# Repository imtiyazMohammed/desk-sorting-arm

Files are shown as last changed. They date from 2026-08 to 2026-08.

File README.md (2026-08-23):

# Autonomous Desk-Sorting Robotic Arm — Phase A

https://github.com/user-attachments/assets/2be9d9cc-dfaf-4284-88d5-a9f24a1ce587



Kinematics simulation (Phase A), computer-vision foundation (Phase B), and
parametric CAD (Phase D). No hardware required to run anything in this
repository.

**Requires Python 3.10-3.14.** `build123d` (Phase D parametric CAD) declares
`requires-python ">=3.10,<3.15"`, so the Python 3.9 support present through
Phase A has been dropped. Raspberry Pi OS Bookworm ships 3.11 and Trixie ships
3.13, so 3.9 is not needed for the deployment target. CI covers 3.10-3.13.

## Quickstart

```bash
# 1. Install dependencies
python3 -m pip install -r requirements.txt

# 2. Run the test suite (449 tests, ~11 seconds)
python3 -m pytest tests/ -v

# 3. Try the module smoke tests
python3 -m src.geometry              # geometry + hardware summary
python3 -m src.forward_kinematics    # FK sanity checks
python3 -m src.inverse_kinematics    # IK sample solves
python3 -m src.trajectory            # trajectory profiling
python3 -m src.image_source          # synthetic camera frames
python3 -m src.camera_calibration    # synthetic calibration vs ground truth

# 4. Generate the CAD parts
python3 -m cad.base_pedestal            # monolithic U-clamp + servo turret
python3 -m cad.desk_clamp_knob          # hand knob
python3 -m cad.desk_clamp_pressure_foot # foot on the clamp screw's tip
python3 -m cad.assembly_preview         # whole assembly on a desk: STL + PNG
#   ... each takes --report (dimensions only) and --output PATH

# 5. Manual hardware tools (need a webcam; not part of the test suite)
python3 scripts/preview_camera.py
python3 scripts/calibrate_camera.py
#   ... both take --synthetic to run without a camera

# 6. Read the proof-of-concept document
docs/PROOF_OF_CONCEPT.md
```

Heavy vision dependencies (`ultralytics`, which pulls in torch) are kept out of
`requirements.txt` until Session B.2 actually imports them:

```bash
python3 -m pip install -r requirements-vision.txt
```

## Repository layout

```
desk_arm/
├── src/
│   ├── geometry.py             # ArmGeometry + hardware specs (source of truth)
│   ├── forward_kinematics.py   # Hand-derived FK using homogeneous transforms
│   ├── arm_chain.py            # ikpy Chain constructor
│   ├── inverse_kinematics.py   # IK with reachability + singularity checks
│   ├── trajectory.py           # Trapezoidal velocity profiler
│   ├── visualizer.py           # 3D matplotlib rendering
│   ├── image_source.py         # ImageSource ABC + synthetic and webcam sources
│   └── camera_calibration.py   # Chessboard intrinsics + synthetic target
├── cad/
│   ├── base_pedestal.py        # Monolithic U-clamp + servo turret (build123d)
│   ├── desk_clamp_knob.py      # Fluted hand knob
│   ├── desk_clamp_pressure_foot.py  # Foot on the clamp screw's tip
│   ├── assembly_preview.py     # All parts placed on a desk (STL + PNG)
│   ├── _design.py              # Shared DesignStatus / DesignRuleError
│   ├── _primitives.py          # Shared solids (hex_prism)
│   ├── output/                 # Generated STLs
│   └── README.md               # Parametric approach, clamp design, assembly
├── scripts/
│   ├── preview_camera.py       # Manual webcam check, not run by CI
│   └── calibrate_camera.py     # Interactive intrinsic calibration
├── tests/
│   ├── test_kinematics.py      # 35 tests - Phase A kinematics
│   ├── test_image_source.py    # 71 tests - Session B.1 image acquisition
│   ├── test_camera_calibration.py  # 100 tests - Session B.2 calibration
│   └── test_cad.py             # 243 tests - Sessions D.1/D.1b/D.1c/D.1d parametric CAD
├── docs/
│   ├── PROOF_OF_CONCEPT.md     # Design + math + validation
│   └── figures/                # Generated diagrams
├── requirements.txt
├── requirements-vision.txt     # Deferred: ultralytics / torch
└── README.md
```

## Design constraints locked in Phase A

| Parameter | Value | Reason |
|---|---|---|
| DOF | 5 (base yaw, shoulder, elbow, wrist pitch, wrist roll) | Enables angled grasps + monitor cleaning |
| Mount position | Center of long desk edge (1200×600 mm desk) | Halves worst-case reach vs corner mount |
| L1 (upper arm) | 400 mm | |
| L2 (forearm) | 350 mm | |
| L3 (wrist → TCP) | 200 mm | |
| Base height | 100 mm | |
| Total reach | 950 mm | Covers 848.5 mm desk diagonal with 12% margin |
| Servos | DS3218 (5×) | 21.5 kg·cm at 6.8 V, digital metal-gear |
| Base pedestal | 70 mm tall, 85.3 mm body | `base_height_mm` 100 − 30 mm stack allowance |
| Desk mount | Monolithic M8 U-clamp, 45 mm throat | No drilling; fits 15–35 mm desks, repositionable |

## Known outstanding items (deferred to later phases)

- **Shoulder torque budget**: 950 mm arm exceeds DS3218 20 kg·cm rating. To be resolved in Phase C via 2:1 gear reduction or dual-servo shoulder.
- **Singularity threshold**: Currently unit-inconsistent (mm-scaled Jacobian). To be normalized before deployment.
- **Orientation IK**: Position-only solves for now. Full pose IK (with grasp orientation) belongs to the grasp planner in Phase E.
- **Unverified servo dimensions**: The DS3218 body envelope is datasheet-confirmed, but its mounting-flange geometry and output-shaft placement are placeholders. See `ServoSpec.UNVERIFIED_FIELDS` and [cad/README.md](cad/README.md); measure a real unit before printing for final assembly.
- **Provisional base stack**: The 6 mm turntable plate and 24 mm shoulder bracket rise that set the pedestal height are estimates, replaced in Sessions D.2/D.3.

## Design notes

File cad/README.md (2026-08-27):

# Parametric CAD

Mechanical parts for the desk-sorting arm, modelled in
[build123d](https://build123d.readthedocs.io/) (a Python CAD library over the
OpenCASCADE kernel).

## The rule: no dimensions live here

Every part in this package derives its dimensions from `src/geometry.py`:

- **`DEFAULT_ARM`** (`ArmGeometry`) — kinematic lengths, the base height
  budget, the base's position on the desk, and the mass estimates the mount is
  sized against.
- **`DEFAULT_HARDWARE`** (`HardwareSpec`) — off-the-shelf component envelopes:
  the DS3218 servo, the 6806ZZ yaw bearing and 608ZZ shoulder idler, the servo
  horn, the M8 desk clamp, print clearances.

No module in `cad/` declares a physical dimension of its own. This is the same
discipline that keeps `arm_chain.py` building its ikpy chain programmatically
instead of from a URDF file: one number, one place, and a change propagates
atomically instead of drifting.

The practical consequence: to make the clamp fit a different servo or a thicker
desk, edit `src/geometry.py`. Do not edit `cad/base_pedestal.py`.

## Regenerating STLs

```bash
python3 -m cad.base_pedestal               # -> cad/output/base_pedestal.stl
python3 -m cad.desk_clamp_knob             # -> cad/output/desk_clamp_knob.stl
python3 -m cad.desk_clamp_pressure_foot    # -> cad/output/desk_clamp_pressure_foot.stl
python3 -m cad.yaw_turntable               # -> cad/output/yaw_turntable.stl
python3 -m cad.shoulder_bracket            # -> shoulder_bracket.stl + shoulder_idler_plug.stl
python3 -m cad.upper_arm                   # -> cad/output/upper_arm.stl
python3 -m cad.assembly_preview            # -> assembly_preview.stl + .png
```

Each module takes `--report` (print resolved dimensions, export nothing) and
`--output PATH`. Run `--report` after changing anything in `src/geometry.py` to
see what moved.

---

## Why a monolithic U-clamp

Session D.1 bolted a flange to the desk through four M4 holes — which meant
drilling the desk. D.1b replaced that with a clamp, but built it as a cylinder
with a small horizontal wing bolted down beside it: a tower with a side arm,
not a clamp. **Session D.1c is a full rewrite as a single C-profile body**, the
shape a monitor-arm clamp actually uses:

```
                      +----------+  z = +70   bearing seat in the top face
                      |  servo   |
                      |  turret  |
      +---------------+----------+---------+  z = +15   top arm
      |///|    pads       cavity opening   |  z =   0   desk surface
      |///+-------------------------------+
      |///|                                |
      |sp |          throat (desk)         |
      |ine|                                |
      |///+-------------------------------+  z = -45   bottom arm top
      |///|         nut pocket    O screw  |
      +---+-------------------------------+  z = -60   bottom arm underside
       -50  -35    -30                   +30
                    ^ desk seats here
```

Everything is one solid: top arm, spine, bottom arm, servo turret and both
gussets. There is no bolted joint anywhere in the load path.

The servo/bearing internals — cavity, retention shelf, shaft bore, seat — are
carried over from D.1 unchanged; `test_pedestal_internals_survived_the_u_clamp_rewrite`
pins those dimensions so a future edit cannot quietly disturb them.

---

## Three specified numbers that could not be built

The design-rule checks and a cross-section render caught three physical
impossibilities in the D.1c brief. All are documented here rather than
silently worked around.

### 1. A 15 mm top arm cannot contain a 40.5 mm servo

`top_arm_thickness_mm = 15.0` was specified as including the servo cavity. A
DS3218 is 40.5 mm tall and needs **55.5 mm** of housing once print clearance,
the shaft boss, a ceiling and the bearing seat are counted.

**Resolved** by keeping the arm at 15 mm and raising a **turret** from it to
the full 70 mm pedestal height. This is what the brief's own sketch showed
(the servo box is drawn above the arm line), it preserves the thin C-profile,
and the 70 mm budget from `base_height_mm − BaseStack.allowance_mm` accepts it
exactly. Thickening the arm instead would have made a slab and tripled its
material.

### 2. The servo cavity and the desk pad both wanted the same face

The cavity has to open on the top arm's underside so the servo can be inserted
from below onto its retention shelf. But that face is also what rests on the
desk and carries the anti-slip pad. A 40 × 40 mm pad has nowhere to go: the
opening lands mid-face, leaving 15.75 mm strips.

**Resolved** with **two pad strips flanking the opening**, 15.75 × 78.50 mm
each — 2473 mm² total, more contact than the single 40 × 40 pad (1600 mm²) it
replaced, and better placed, since it straddles the yaw axis instead of sitting
to one side.

### 3. A 20 mm pad recess cannot sit on an 8 mm screw tip

**Resolved** with a small printed **pressure foot** (`desk_clamp_pressure_foot.py`)
that threads onto the screw's tip and carries the pad. See below.

### And one the cross-section caught

The upper gusset hangs into the throat beside the spine, so the desk's edge
comes to rest **against the gusset, not the spine**. With the spine placed at
the nominal offset, the yaw axis would have ended up 25 mm from the desk edge
rather than the specified 30 mm.

**Resolved** by treating the gusset line as the real desk seating plane and
placing the spine one gusset further out (`spine_inner_x = desk_seat_x −
gusset_size`). `test_the_gusset_defines_where_the_desk_stops` holds it.

---

## Parts

### `base_pedestal.py` — the U-clamp

| | |
|---|---|
| Overall envelope | 80.00 (X) × 82.50 (Y) × 129.50 (Z) mm |
| Desk seats at | x = −30.00 mm (yaw axis at x = 0) |
| Top arm | x −35 … +30, z 0 … 15 |
| Spine | x −50 … −35, z −60 … +15 |
| Bottom arm | x −35 … +30, z −60 … −45 |
| Throat | 45.0 mm, for 15–35 mm desks |
| Servo turret | x ±24.95, y −41.25 … +24.95, z 15 … 69.5 |
| Servo cavity | 20.50 (X) × 40.50 (Y) body, 54.50 (Y) ear slot |
| Bearing seat | Ø41.90 × 6.50 mm deep (6806ZZ since D.2a) |
| Anti-slip pads | 2 × 15.75 × 78.50 mm, 2.0 mm deep (2473 mm²) |
| Clamp screw | Ø9.00 through the bottom arm at x = −16.00 |
| Volume | ≈ 356 cm³ |

**Coordinate frame.** The origin is on the yaw axis at the **desk's top
surface**, so `z = 0` is the desk plane and `+X` points inward over the desk.
This is deliberate: `ArmGeometry.base_height_mm` is measured from the same
datum, so the clamp, the kinematics and the assembly preview share one
coordinate system with no conversion step. The exported STL therefore straddles
z = 0 rather than sitting on the bed — slicers drop it on import.

**Why the servo's long axis runs across the clamp.** Along the arm it does not
fit: the ear slot is 54.5 mm and the body sits 10 mm off the shaft, so it would
reach 37.25 mm from the axis and break out past a spine only 30 mm away. Across
the clamp, the arm needs to be just 20.5 mm deep for it. This is what sets the
clamp's 82.5 mm width.

**Why the screw sits outboard, not under the yaw axis.** Placing it as far
toward the desk edge as the pressure foot allows shortens the bottom arm's
cantilever (19 mm instead of 30) *and* lengthens the lever it resists tipping
with (46 mm instead of 30) — both improve at once.

**Why gussets rather than fillets.** A swept fillet is the most fragile
operation to re-run when an upstream dimension moves, and every dimension here
is expected to move. Triangular gussets give most of the stress relief and
always regenerate.

### `desk_clamp_pressure_foot.py`

| | |
|---|---|
| Foot | Ø24.00 × 6.02 mm |
| Swivel seat (underside) | Ø9.00 mouth → Ø2.00 flat, 2.02 mm deep, 120° included |
| Web | 2.00 mm (compression only) |
| Pad recess (top) | Ø20.00 × 2.00 mm deep |
| Contact area | 314 mm², **6.2× a bare M8 tip** |

Rests on the screw's tip and bears on the desk's underside. Its height is not a
free choice: at the thickest supported desk the throat leaves exactly 10 mm
between the bottom arm and the desk, and the foot has to fit inside that.
`validate()` enforces it.

**Revised in D.1d: it swivels, it does not thread on.** The first version had a
tapping bore, so the foot turned with the screw. That drags the rubber pad
across the desk as you tighten — scuffing the finish — and moves the friction
that resists tightening out to the pad's radius, which roughly halves the
preload a given hand torque produces. Seated on a truncated cone the foot is
free to stay still while the screw turns inside it. The cone's apex is
truncated because a sharp internal point is unprintable and tessellates to
degenerate triangles.

The foot is not captive: it rests on the tip and drops off if the assembly is
inverted. Fit it as the clamp goes on; once the pad meets the desk it stays put.

### `desk_clamp_knob.py`

| | |
|---|---|
| Body | Ø50.00 × 20.00 mm |
| Hex socket (top) | 13.10 mm across flats × 7.80 mm deep |
| Shank bore | Ø9.00 × 12.20 mm |
| Grip flutes | 12 × Ø8.00 mm scallops |

**Why it stayed 50 mm.** The knob was scheduled to shrink to 30 mm, on the
grounds that a large knob lets a hand exceed the printed jaw's 3.9 N·m limit.
That limit belonged to D.1b's cantilever wing. The U-clamp's bottom arm takes
**7.89 N·m** and a 50 mm knob reaches only 1.00 N·m — 7.9× of headroom — so
there is nothing left to protect against, while shrinking would have cut the
grip margin from 3.51× to 2.11×. The shrink was cancelled.

(Those two figures were 11.62 N·m and 2.39× when the shrink was cancelled in
D.1c; D.1d's corrected friction model moved both. The conclusion is unchanged —
the headroom is smaller but still far beyond a hand.)

**The bearing boss is gone (D.1d).** It was added in D.1b, where the knob bore
against the upper jaw and collar friction there ate much of the hand torque. In
the U-clamp the knob touches nothing but the screw — the assembly preview shows
it hanging 28 mm below the bottom arm — so the boss was inert material and the
friction term it justified was modelling a contact that does not exist.

Print **socket-face down**: no support needed and the gripping surfaces come
out crisp.

### `yaw_turntable.py` — D.2a

| | |
|---|---|
| Plate | Ø68.00 × 6.00 mm |
| Spigot in the bearing bore | Ø29.50 × 7.00 mm |
| Horn pocket | Ø25.50 × 6.00 mm deep, 2.00 mm ring wall |
| Outer-race relief | Ø33.00 … Ø42.50 × 1.00 mm deep |
| Land on the inner ring | 1.75 mm wide |
| Horn screws | 4 × Ø3.40 on a Ø16 circle, counterbored Ø6.00 × 3.50 |
| Bracket screws | 4 × Ø2.50 blind × 4.00 mm on a 52 × 20 mm rectangle |
| Volume | ≈ 22 cm³ (28 g) |

**Origin on the land plane** — the face that touches the bearing's inner ring —
which is desk-frame z = 70.0. The plate sits above it, the spigot hangs below.

**Why the underside is stepped.** The bearing stands 0.5 mm proud of the
turret. A flat underside would land on the printed turret face; a plain recess
deeper than 0.5 mm would do the same while also clearing the inner ring. So the
relief covers the **outer** ring only and the plate lands on the inner ring
inside it. That is what makes the bearing a bearing rather than a spacer, and
it is the correction to the brief's `bearing_race_recess_mm`.

**Why the bolt pattern is a rectangle, not a circle.** The screws must clear
the bearing relief (radius 21.25 mm) *and* miss the bracket's two walls, which
stand on the plate between y = 15.5 and 21.5 mm. A circle large enough for the
first crosses the second at every phase angle unless its diameter passes 66 mm,
by which point it is off the plate. A 52 × 20 mm rectangle satisfies both and
leaves all four heads reachable from above, between the walls.

**Why the plate is Ø68 and not "slightly larger than the turret".** The turret
is not round: 49.9 × 66.2 mm, an 82.9 mm diagonal. A disc that covered it would
overhang the 60 mm-deep top arm it stands on. What the plate has to cover is
the bearing, and Ø68 does that with 13 mm of rim.

**The yaw-zero mark is a witness notch, not a key.** A true key is impossible
against a round horn whose four holes sit on a square — the pattern is
symmetric under 90° rotation, so any mating feature fits four ways, and keying
it would mean filing a flat on a bought part. The notch in the rim lines up
with the turret's front face at yaw zero.

**Tightest feature: the 2.00 mm ring** between the horn pocket and the bearing
bore, exactly at its floor of half the minimum wall. Half is allowed because
the ring is confined by the steel race over its whole height — the same
allowance the pressure foot's rim takes. A horn narrower than Ø25 (Ø19.7 is
also sold) doubles the margin.

### `shoulder_bracket.py` — D.2b

| | |
|---|---|
| Base plate | x −40.25 … +31.75, y ±21.50, 6.00 mm thick |
| Walls | x −40.25 … +20.25, z 6.00 … 34.50, inner faces at y ±15.50, 6.00 mm thick |
| Servo slot | 40.50 (X) × 31.00 (Y) × 20.50 (Z) mm, open at the top |
| Servo screws | 4 × Ø3.00 blind × 4.50 mm |
| Pitch axis | z = 24.00 local, **100.000 mm above the desk** |
| Horn face | y = 35.50 mm |
| Volume | ≈ 30 cm³ (38 g), plus the idler plug at ≈ 11 cm³ (13 g) |

**The reason the part exists** is the last line of that table. Pedestal 69.5 +
bearing proud 0.5 + turntable 6.0 + this rise 24.0 = 100.000 mm, which
`test_shoulder_shaft_height_matches_base_height` checks against
`ArmGeometry.base_height_mm` rather than against a copy of the number.

**The servo lies on its side because it must.** Stood on end, its ears are
49.5 mm apart along the body, so at a 24 mm rise the lower one lands 0.75 mm
*below* the turntable the bracket is bolted to. Laid down, the 20 mm width
straddles the axis from 14 to 34 mm and both ears are reachable — and every
part of the bracket stays within 47 mm of the pitch axis, which is what lets
the upper arm's yoke swing.

**Both walls are identical.** The undriven one takes the idler plug today; a
reduction plate or an alternative actuator bolts to the same four holes.
See the limit on the twin-servo option in `docs/PROOF_OF_CONCEPT.md` §2.3.

**The cable leaves at the rear, not down the yaw axis.** The yaw servo's shaft
and its horn fill that axis solid from the turret to the turntable's cap, so
the notch is in the base plate's rear edge, outside the turntable's rim. Allow
a service loop for ±135° of yaw travel.

The base plate overhangs the turntable by about 12 mm at its rear corners. That
is expected, not a modelling error: the plate is sized by the servo's 54.5 mm
flange and the disc by the bearing, and the bolt pattern that carries the load
sits well inside the disc.

### `upper_arm.py` — D.2c

| | |
|---|---|
| Axis to axis | 400.00 mm (`ArmGeometry.l1_upper_arm_mm`) |
| Beam section | 40.00 (Y) × 25.00 (Z) mm, 3.00 mm walls, hollow |
| Beam run | x 49.16 … 365.75 |
| Driven flange | y 35.50 … 41.50, Ø36.00, horn recess + 4 counterbored screws |
| Idler flange | y −45.50 … −35.50, Ø21.90 × 7.00 bearing seat |
| Yoke width | 87.00 mm overall |
| Elbow housing | x 365.75 … 414.25, y ±21.50, z ±14.25 |
| Cable trough | 8 × 8 mm open channel on the top face, 3 strain-relief tabs |
| Volume | ≈ 209 cm³ (265 g) |

**A yoke, not a flange.** The shoulder horn's face is 35.5 mm off the yaw axis,
so a link hung off one flange would centre roughly 50 mm to one side — and
`forward_kinematics.py` models no shoulder offset, so that would become
systematic error in every computed TCP position. Two flanges straddle the
bracket: the driven side bolts to the horn, the undriven side runs the 608ZZ
on the idler plug's axle.

**Stress is not what sizes the section.** At the 3.26 N·m worst-case shoulder
moment the section carries **1.25 MPa** against a 25 MPa allowable — 20× — and
deflects about 2.7 mm. The section is kept because it is stiff and it packages
the elbow servo's cabling. Its cost is mass: 265 g, which is most of what §2.2
budgeted for the entire arm's plastic.

**The 3 mm wall is an explicit exception to `min_wall_thickness_mm`.** The 4 mm
floor was set for the clamp's load-bearing walls; 3 mm is still seven
perimeters at a 0.4 mm nozzle, and taking these walls to 4 mm would add ~29 %
to the mass of a link with a 20× stress margin.

**The trough stands on the beam rather than being cut into it.** An 8 mm
channel sunk into a 3 mm top wall does not stay a channel — it breaks through
into the hollow and turns a closed box into an open section, losing roughly
sixty times its torsional stiffness. The trough is a raised U instead, so the
channel is still open for wires to drop into and the box below is intact.

**The elbow servo does not fit inside the beam.** Its smallest dimension is
20 mm and its largest is 40.5; a 40 × 25 mm section cannot swallow it in any
orientation once walls are counted. The distal end swells into a housing built
the same way as the shoulder bracket — two walls, a top-open slot, four blind
screws — so `L2` will straddle it exactly as `L1` straddles the shoulder.

---

## Clamp mechanics

| | | revised in D.1d |
|---|---|---|
| Arm tipping moment (worst case) | 6.76 N·m | unchanged |
| Tipping lever (top arm edge → screw) | 46.00 mm | unchanged |
| Preload needed | **147 N** | unchanged (0.28 N·m at the knob, was 0.42) |
| Hand torque available, Ø50 knob | 1.00 N·m | unchanged |
| Preload it produces | **516 N** | ← was 350 N |
| **Grip margin** | **3.51×** | ← was 2.39× |
| Bottom arm structural limit | 7.89 N·m | ← was 11.62 N·m |

**Why those three numbers moved.** The friction model charged collar friction
at the knob boss's radius, about 6.75 mm, for a contact the U-clamp does not
have. D.1d moved it to where the rubbing actually happens — the screw's tip
turning in the pressure foot's cone, contact radius 3.20 mm — which roughly
halves the friction lever and so raises the preload a given torque produces.
The structural limit falls in the same proportion, because it is expressed as a
*torque* and the same torque now delivers more force; the *force* the bottom
arm can carry is unchanged at 4834 N. Hand torque still cannot reach it.

**The U-profile inverts the old design's weakness.** D.1b's side wing yielded
at 3.9 N·m — below what a hand could apply — so `cad/README.md` had to carry a
"do not use a wrench" warning. A 15 mm bottom arm spanning the full 82.5 mm
width takes 7.89 N·m, which no hand can reach through a knob this size. That
is a structural guarantee rather than an instruction, and
`test_hand_cannot_overstress_the_u_clamp` holds it.

The tipping moment above is deliberately pessimistic: it puts the whole arm
mass plus a full payload at maximum reach. `docs/PROOF_OF_CONCEPT.md` §2.2
computes ≈ 3.4 N·m on a real centre-of-mass basis, so the true grip margin is
roughly double the figure quoted.

---

## Design rule checks

Every part's `validate()` re-derives each clearance and refuses to build
something that would print badly, raising a `DesignRuleError` subclass carrying
a `DesignStatus` from `cad/_design.py`.

| Check | `DesignStatus` on failure |
|---|---|
| **U-clamp** | |
| Base height budget leaves room for the turret | `NEGATIVE_HEIGHT` |
| Vertical order: top arm < ear shelf < cavity ceiling < bearing seat | `FEATURE_COLLISION` |
| Ceiling between cavity and bearing seat ≥ `min_wall_thickness_mm` | `WALL_TOO_THIN` |
| Turret walls clear the cavity *and* the bearing seat | `WALL_TOO_THIN` |
| Turret sits within the top arm, not overhanging it | `FEATURE_COLLISION` |
| Spine outer < spine inner ≤ desk seating plane | `INVALID_PARAMETER` |
| Gussets do not close the throat from both sides | `FEATURE_COLLISION` |
| Pad strips have area left between cavity and gusset | `FEATURE_COLLISION` |
| Screw is inboard of the desk seat; foot stays under the desk | `FEATURE_COLLISION` |
| Floor above the nut pocket ≥ `min_wall_thickness_mm` | `WALL_TOO_THIN` |
| Nut pocket clears the spine and the clamp's sides | `WALL_TOO_THIN` |
| M3 pilot holes land in shelf material | `FEATURE_COLLISION` |
| Screw long enough to reach the *thinnest* supported desk | `FASTENER_TOO_SHORT` |
| **Pressure foot** | |
| Height matches bore + web + pad recess | `INVALID_PARAMETER` |
| Foot fits the throat at the thickest desk | `FEATURE_COLLISION` |
| Bore inside pad recess inside foot | `FEATURE_COLLISION` |
| **Knob** | |
| Hex socket does not pierce the knob | `FEATURE_COLLISION` |
| Bearing boss leaves a wall around the bore | `WALL_TOO_THIN` |
| Flutes do not cut into the socket or reach the boss | `WALL_TOO_THIN` |
| **Yaw turntable** | |
| Race relief deeper than the bearing stands proud | `FEATURE_COLLISION` |
| Relief starts outside the spigot, leaving a land | `FEATURE_COLLISION` |
| Horn shorter than the bearing is wide, leaving a cap | `FEATURE_COLLISION` |
| Ring around the horn pocket >= half the minimum wall | `WALL_TOO_THIN` |
| Horn counterbores stay inside that ring | `FEATURE_COLLISION` |
| Bracket bolts clear the bearing and keep a rim | `FEATURE_COLLISION` / `WALL_TOO_THIN` |
| Bracket bolts stay blind, with a floor above the bearing | `FEATURE_COLLISION` |
| **Shoulder bracket** | |
| The stack lands the pitch axis on `base_height_mm` | `INVALID_PARAMETER` |
| Servo clears the base plate, and its ears are reachable | `FEATURE_COLLISION` |
| Servo screws land in wall, not in the slot | `FEATURE_COLLISION` |
| Blind servo screws keep a floor in the wall | `WALL_TOO_THIN` |
| Walls stand within the base plate | `FEATURE_COLLISION` |
| Turntable screws miss the walls and keep an edge | `FEATURE_COLLISION` / `WALL_TOO_THIN` |
| Cable slot misses the walls and the screws | `FEATURE_COLLISION` |
| Idler axle long enough to reach its bearing | `INVALID_PARAMETER` |
| **Upper arm** | |
| Bending stress below the PETG allowable | `INVALID_PARAMETER` |
| Beam starts outside everything the bracket occupies | `FEATURE_COLLISION` |
| Yoke flanges clear the beam's width | `FEATURE_COLLISION` |
| Flanges leave a wall around horn recess and bearing seat | `WALL_TOO_THIN` |
| Elbow housing does not overlap the yoke | `FEATURE_COLLISION` |
| Cable trough narrower than the beam it stands on | `FEATURE_COLLISION` |

Note the screw-length check keys off the **thinnest** desk, not the thickest: a
thin desk sits high in the throat, so its underside is furthest from the bottom
arm and the screw has to reach hardest.

---

## Assembly

### 1. Print the parts

| Part | Orientation | Notes |
|---|---|---|
| `base_pedestal` | Spine face down on the bed | The U's opening faces sideways; no supports needed for the throat |
| `desk_clamp_knob` | Hex socket **down** | Crisp socket, no supports |
| `desk_clamp_pressure_foot` | Pad recess **up** | Bore bridges cleanly |
| `yaw_turntable` | Spigot **up** | The plate's face lands on the bed; the race relief bridges |
| `shoulder_bracket` | Base plate down | Walls print upright; the servo slot is open at the top |
| `shoulder_idler_plug` | Plate face down, axle up | The axle is a short tower, no supports |
| `upper_arm` | On its side, one yoke flange on the bed | The trough and both flanges then print without overhangs |

PETG throughout, ≥ 4 perimeters. The design assumes 4 × 0.4 mm walls
(`min_wall_thickness_mm = 4.0`); the upper arm's 3 mm beam walls are an
explicit, documented exception.

### 2. Glue in the anti-slip pads

Cut from 2 mm rubber sheet:

- **Two 15.75 × 78.50 mm strips** for the top arm's underside
- **One Ø20 mm disc** for the pressure foot's top face

Degrease both rubber and printed recess with isopropyl alcohol, then bond with
contact adhesive or cyanoacrylate. The recesses are 2.0 mm deep and the sheet
is 2.0 mm, so a correctly seated pad sits **flush** — `DeskClampSpec` refuses a
pad thicker than its recess for exactly this reason.

### 3. Press the M8 nut into the bottom arm

The hex pocket is in the bottom arm's **underside**. It should need a firm
push. If it spins, a drop of epoxy locks it; it only ever resists the screw's
thread friction.

### 4. Fit the knob and the foot to the screw

Press the M8 × 70 screw's hex head into the knob's socket until it bottoms out,
7.80 mm down. The pressure foot simply **rests** on the other end: its conical
seat centres on the screw's tip. It is not captive — hold it in place while
positioning the clamp, and it stays put once the pad meets the desk.

### 5. Thread the screw up through the bottom arm

From below: knob at the bottom, screw rising through the captive nut, foot on
top pointing at the desk. Wind it down so the foot sits low in the throat.

### 6. Clamp to the desk

1. Slide the clamp onto the desk edge until the desk stops against the gussets.
2. Check both pad strips are fully on the desk and the foot is under solid desk.
3. Turn the knob until firm. The bottom arm cannot be over-stressed by hand, so
   "firm" is enough — there is no torque warning to observe on this design.

### 7. Build the base stack (D.2)

1. Press the **6806ZZ** into the turret's top face. It should stand 0.5 mm
   proud; that gap is what the turntable rides on.
2. Fit a **25T round horn** to the yaw servo's spline and drive its retaining
   screw. Note which spline tooth you used — the coupling re-indexes in 14.4°
   steps.
3. Lower the **yaw turntable** on: its spigot enters the bearing's bore and its
   underside meets the horn's disc. Four M3 screws pass down through the plate
   into the horn's threads, heads sunk in the counterbores so nothing stands
   proud. Line the rim's witness notch up with the turret's front face at yaw
   zero.
4. Bolt the **shoulder bracket** down with four M3 into the turntable's blind
   holes. Do this before the servo goes in — afterwards the screws are behind
   it.
5. Drop the **shoulder servo** into the slot from above, ears against the
   driven wall, and drive four M3 into that wall's blind holes. Reach through
   the far wall's slot with the driver; that is what it is open for. Route its
   lead out through the base plate's rear notch and leave a service loop long
   enough for ±135° of yaw.
6. Press a **608ZZ** into the upper arm's idler flange, then bolt the **idler
   plug** to the far wall so its axle points at that bearing.
7. Fit the second horn to the shoulder servo, then bring the **upper arm** in
   from the front: the idler flange's bearing goes onto the plug's axle and the
   driven flange onto the horn. Four M3 through the driven flange finish it.

---

## Assembly preview

```bash
python3 -m cad.assembly_preview                      # STL + PNG
python3 -m cad.assembly_preview --report             # summary only
python3 -m cad.assembly_preview --desk-thickness 35  # any desk in range
```

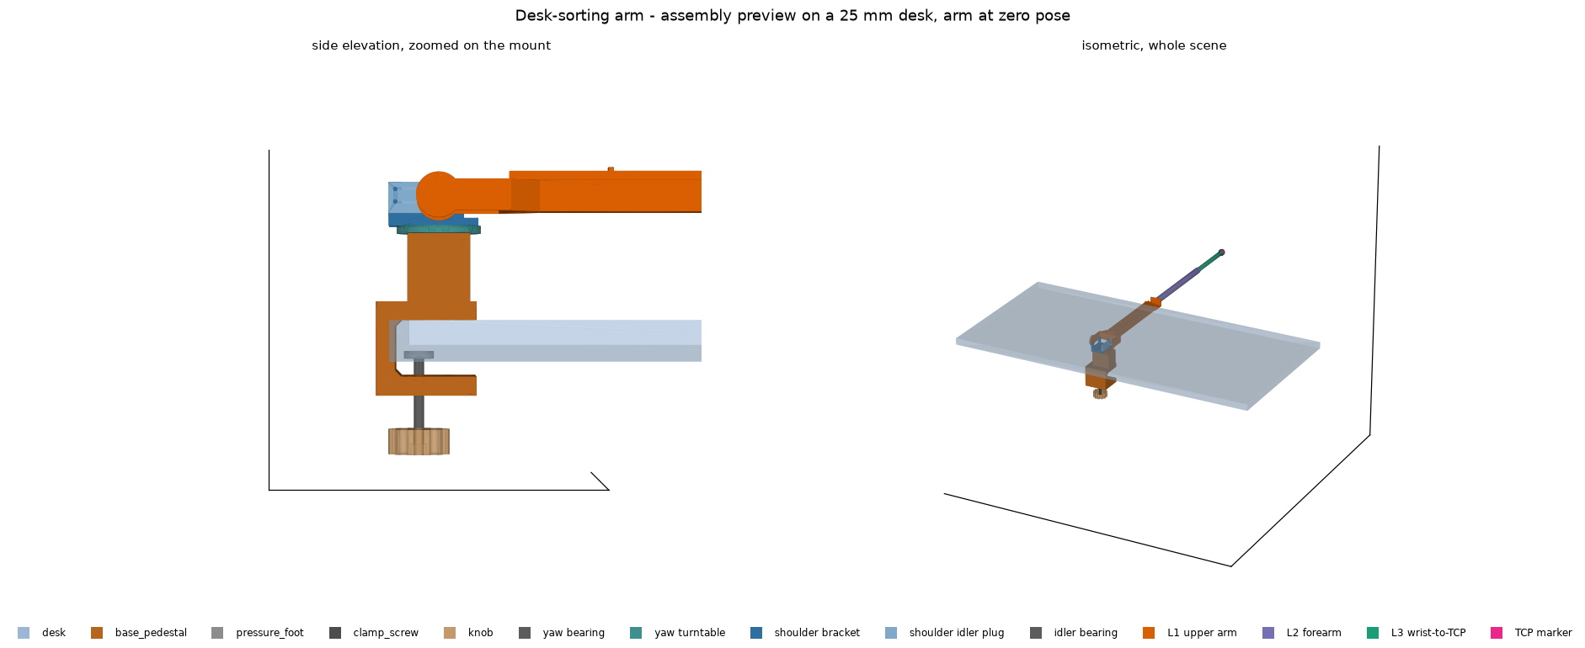
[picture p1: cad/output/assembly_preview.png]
Assembly preview


Every part placed on a 1200 × 600 mm desk at the position `ArmGeometry`
actually specifies. Since Session D.2 everything from the clamp up to the elbow
is a **real part**; only L2 and L3 are still placeholder cylinders, waiting on
D.3. Individual parts each pass their own design rules, but nothing else checks
that they *fit together on a real desk* — this does, and `tests/test_cad.py`
asserts the same properties numerically rather than relying on the picture,
including a pairwise intersection check across the whole base stack.

| | |
|---|---|
| Yaw axis on desk | (600.0, 30.0) mm |
| Clamp footprint | 82.5 (X) × 80.0 (Y) mm |
| Shoulder pivot | z = 100.0 mm |
| Elbow pivot | (600.0, 430.0, 100.0) mm |
| Knob hangs below the bottom arm | 28.1 mm (on a 25 mm desk) |
| Printed volume | 661.3 cm³ solid |
| Estimated filament | ≈ 294 g PETG at 35% infill |

The arm at zero pose reaches 980 mm along +Y, well past the desk's 600 mm
depth. That is correct rather than alarming: the zero pose is a fully extended
horizontal reference posture, not a working position.

The scene is exported as a single STL with each solid left as its own closed
shell — a scene, not a manufacturable part. Rendering uses matplotlib over the
tessellated mesh, because build123d's own viewers need a live GUI session and
are unusable from a script or in CI.

---

## ⚠ Unverified dimensions

The DS3218 body envelope (40 × 20 × 40.5 mm), mass, gear ratio, torque and speed
are confirmed against the DSServo product datasheet. **The mounting-flange
geometry and output-shaft placement are not.** The datasheet's dimensioned
drawing is a raster image with no extractable numbers, and suppliers ship
visually similar variants.

These fields carry standard-size-servo placeholders and are enumerated in
`ServoSpec.UNVERIFIED_FIELDS`:

```
flange_span_mm  flange_thickness_mm  flange_hole_spacing_long_mm
flange_hole_spacing_short_mm  flange_hole_diameter_mm
shaft_offset_from_body_end_mm  shaft_boss_diameter_mm
shaft_boss_height_mm  output_shaft_diameter_mm  travel_deg
```

### The servo horn -- one verified number, the rest placeholders

Session D.2a added `ServoHornSpec`, the coupling both the yaw turntable and the
upper arm bolt to. Only the spline is confirmed: the DS3218's 25T output is
**5.9 mm** across, which is why nothing here tries to print a mating spline
(the tooth pitch works out at 0.74 mm, under two extrusion widths).

Everything describing the horn itself is a placeholder and is listed in
`ServoHornSpec.UNVERIFIED_FIELDS`:

```
disc_diameter_mm  disc_thickness_mm  hub_diameter_mm
hub_height_mm  bolt_circle_mm  bolt_count
```

Round 25T horns are sold at 19.7, 24.5 and 25 mm across, and hole patterns vary
between makers. The defaults describe a 25 mm disc with four M3 holes on a
16 mm circle, which is at least self-consistent -- that leaves 4.5 mm of rim,
enough for M3. Two consequences are worth knowing before ordering:

- **`disc_diameter_mm` sets the minimum bearing bore.** It is why the yaw
  bearing is a 6806 and not a 608.
- **`total_height_mm` (6 mm) has only 1 mm of margin** against the bearing's
  7 mm width. A taller horn would lift the turntable off its race;
  `HardwareSpec` refuses that outright and names the fix.

`BearingSpec.inner_race_outer_diameter_mm` is also unverified -- bearing tables
publish bore, OD and width but rarely the ring split. The 33 mm default is a
deliberate under-estimate, so the turntable's land stays on the inner ring even
if it is optimistic by a millimetre.

`python3 -m src.geometry` and `python3 -m cad.base_pedestal` both print these
lists every run. **Measure a real DS3218 before printing for final assembly** —
`flange_span_mm` now sets the clamp's whole width, and
`shaft_offset_from_body_end_mm` shifts the cavity within it.

Also confirm which **travel variant** was ordered. The DS3218 ships in 180° and
270° versions; `ArmGeometry`'s base yaw limit is ±135° (a 270° span), which the
180° variant cannot deliver.

### Clamp fastener dimensions — verified, with one caveat

| | Value | Source |
|---|---|---|
| M8 coarse thread pitch | 1.25 mm | ISO 261 |
| Hex head across flats / height | 13.00 / 5.30 mm | DIN 933 / ISO 4017 |
| Clearance hole (medium series) | 9.0 mm | ISO 273 |
| Nut across flats | 13.00 mm max | DIN 934 |
| **Nut thickness** | **6.80 mm max** | **DIN EN ISO 4032** |

Legacy DIN 934 tables give m = 6.5 mm max for M8; the current DIN EN ISO 4032
revision gives 6.80 max / 6.44 min. **Both are sold as "DIN 934."** A pocket cut
to 6.5 mm would not seat a modern nut, so `nut_pocket_depth_mm` derives from the
larger figure.

---

## Reach (resolved in D.1d)

Moving the base 30 mm inward for the clamp improves the worst desk corner from
848.5 mm to **827.6 mm** — the mount offset is a small reach win, not a cost.

That figure sat outside the old `safe_reach_mm` of 807.5 mm (85% of full
extension) while still inside the 89% the links were sized against, so
`coverage_report()` reported "Full-desk reachable? False" for an arm that was
fine. Session D.1d raised `SAFE_REACH_FRACTION` to **0.88** (836.0 mm), which
covers the corner with 8.4 mm to spare, and the report now reads True.

---

## Known future work

- **The clamp is over-material.** At ≈ 356 cm³ it is mostly solid; lightening
  pockets in the spine and arms would cut print time substantially. Deferred
  until the shoulder loads from Session D.3 are known.
- **`BaseStack` is settled for the base.** The 6 mm turntable plate and 24 mm
  shoulder bracket rise are now the real parts' dimensions, and `HardwareSpec`
  refuses to hold a budget that disagrees with them.
- **The arm's mass estimate is stale.** `estimated_arm_mass_kg` is still Phase
  A's 0.625 kg, but L1 alone weighs 265 g. Revise it in Session D.3, when L2
  and L3 exist -- see `docs/PROOF_OF_CONCEPT.md` section 2.3.
- **The pedestal grew with the bearing.** Taking the yaw bearing to a 6806 put
  the turret at x +/-24.95 and the clamp at ~356 cm3. The lightening pockets
  below are now worth more than they were.
- **The stress model is a hand calculation.** A rectangular-section cantilever
  with a point load is a reasonable first approximation, but it ignores the
  spine's restraint and PETG's anisotropy between layers. If the clamp is ever
  asked to carry more, this deserves FEA rather than a bigger safety factor.

## Testing

`tests/test_cad.py` covers hardware-spec validation, clamp physics, parameter
derivation for every part, all the design rule checks, solid construction, and
STL integrity. Since D.2 it also sweeps the shoulder joint's whole travel
looking for a collision between the upper arm and the bracket it straddles, and
intersects every pair of solids in the assembly at the zero pose. The mesh checks parse each exported STL directly rather than
trusting the kernel, because "watertight" is a property of the tessellation a
slicer will read:

- every **undirected** edge used by exactly two faces (closed surface)
- every **directed** edge traversed exactly once (consistent winding)
- enclosed volume positive, and within 1% of the kernel's B-rep volume

```bash
python3 -m pytest tests/test_cad.py -v
```

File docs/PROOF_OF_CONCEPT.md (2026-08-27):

# Proof of Concept — Phase A: Kinematics Simulation

**Autonomous Desk-Sorting Robotic Arm**
Date: 2026-08-22
Phase: A (Simulation only, no hardware)
Status: Complete — 32/32 tests passing.

---

## 1. Purpose and Scope

Phase A validates that a chosen arm geometry can, in principle, reach the required workspace before any hardware is bought, printed, or wired. It answers three questions on a laptop, where mistakes are free:

1. Can this arm physically reach every point it needs to?
2. Do the inverse-kinematics solutions respect the servo joint limits?
3. Will the motion between two poses be smooth enough that the servos survive it?

If any answer is "no", we redesign the geometry before spending money on filament, servos, or bearings. This document records the design decisions, the math behind them, the code that implements them, and the test results that back them up.

Phase A **explicitly excludes**: any physical hardware, computer vision, camera calibration, preference learning, or the PCA9685 servo driver. Those belong to Phases B, C, D, and F respectively.

---

## 2. Design Decisions Locked in Phase A

| Decision | Value | Justification |
|---|---|---|
| Degrees of freedom | 5 revolute + 1 gripper | 5 DOF is the minimum for angled approaches needed by the "monitor cleaning" extension. 4 DOF permits only top-down grasps. 6 DOF was ruled out as overkill for desk work. |
| Joint chain | base yaw → shoulder pitch → elbow pitch → wrist pitch → wrist roll | Standard anthropomorphic layout. Base yaw covers all desk azimuths; three collinear pitch joints span the sagittal plane; wrist roll orients the end-effector. |
| Base mount location | Center of the 1200 mm long edge | Corner mount required 848.5 mm × √2 ≈ 1342 mm reach — infeasible with DS3218 torque. Center-edge mount cuts worst case to 848.5 mm. |
| Desk dimensions | 1200 mm × 600 mm | User's actual desk. |
| L1 (upper arm) | 400 mm | Longest link — dominates leverage but needed for elbow-up geometry. |
| L2 (forearm) | 350 mm | Standard 0.875× L1 proportion. |
| L3 (wrist → TCP) | 200 mm | Includes gripper body length. |
| Base height | 100 mm | Clears typical desktop clutter (books, mouse). **Since D.1c this is a budget, not just a clearance** — see below. |
| Total reach L1+L2+L3 | 950 mm | Exceeds 848.5 mm worst-case corner by 12%. |
| Servo dynamic derating | 60 % of no-load speed | Empirical safety factor for loaded motion. |

### 2.0 Base Height as a Budget (added D.1d)

`base_height_mm` began life in Phase A as a single design input: 100 mm of
clearance over desk clutter. Once the D.1c U-clamp existed it also became a
**budget that the hardware has to add up to**, measured from the desk surface
to the shoulder pivot:

| Component | Height | Source |
|---|---|---|
| U-clamp pedestal, desk surface → turret top | 69.5 mm | derived (whatever is left) |
| Yaw bearing standing proud of the turret | 0.5 mm | `BearingSpec.proud_mm` (a 6806ZZ since D.2a -- see §2.3) |
| Yaw turntable plate | 6.0 mm | `BaseStack`, realised in D.2a |
| Shoulder bracket rise | 24.0 mm | `BaseStack`, realised in D.2b |
| **Total = shoulder pivot** | **100.0 mm** | `ArmGeometry.base_height_mm` |

The pedestal's height is the *dependent* term: it is `base_height_mm` less
everything stacked above it. That is why the servo shaft output sits at
z = 63.0 mm and the turret top at 69.5 mm, both well below the 100 mm pivot —
the 37 mm between them is occupied hardware, not slack.

Session D.1d folded the bearing's 0.5 mm proud height into this budget. It had
been treated as a modelling constant inside `cad/`, which left the shoulder
pivot 0.5 mm high: the turntable rides the bearing's inner race, which stands
above the turret's top face rather than flush with it.

### 2.1 Reach Sizing — the Math

The worst-case pick point is the corner of the desk farthest from the base.

**Phase A**, with the base on the desk edge at `(600, 0)`:

```
d_worst = sqrt( 600^2 + 600^2 ) = 848.528 mm     (0.893 of full extension)
```

**Since D.1c**, the U-clamp holds the yaw axis 30 mm inward of the desk edge,
so the base sits at `(600, 30)` and the farthest corners `(0, 600)` and
`(1200, 600)` move slightly closer:

```
d_worst = sqrt( 600^2 + 570^2 ) = 827.587 mm     (0.871 of full extension)
```

The mount offset is a small reach *win*, not a cost.

A serial revolute arm loses reach very rapidly as it approaches full extension
because Jacobian rank deficiency (a singularity) sends joint velocities toward
infinity. We therefore design so that the worst-case target sits at ~89 % of
theoretical reach:

```
L_total_required = d_worst / 0.89 ≈ 953 mm
Actual choice: L_total = 400 + 350 + 200 = 950 mm
```

### Safe reach ceiling — raised in D.1d

`ArmGeometry.safe_reach_mm` is a separate, more conservative caution line:
`SAFE_REACH_FRACTION × total_reach_mm`. Phase A set that fraction to 0.85
(807.5 mm), comfortably below the 0.89 the links were sized against.

Once D.1c placed the base at `(600, 30)`, the far corners sat at 827.6 mm —
*outside* the 0.85 line while still inside the 0.89 design envelope, so
`coverage_report()` printed "Full-desk reachable? False" for an arm that was
fine. A recommended operating radius that excludes the corners the arm was
built to reach is not a caution, it is a contradiction.

Session D.1d raised the fraction to **0.88** (836.0 mm), which covers the
827.6 mm corner with 8.4 mm to spare and still sits inside 0.89. Two tests
pin it from both sides:

- `test_safe_reach_covers_worst_desk_corner` — fails if the ceiling is ever
  lowered back below the corners.
- `test_design_is_no_safer_than_documented` — an inverted assertion that fails
  if utilisation drifts *away* from ~89 %, so a link change cannot silently
  leave this section describing a design that no longer exists.

### 2.2 Torque Budget — Honest Disclosure

At the shoulder joint, torque is the arm and payload weight multiplied by their horizontal moment arm. Worst case (arm horizontal, fully extended, holding a 100 g pen):

```
τ_payload = (0.100 kg)(0.950 m)(9.81 m/s^2) = 0.932 N·m ≈ 9.5 kg·cm
τ_arm     ≈ (0.625 kg)(0.400 m)(9.81 m/s^2) = 2.45  N·m ≈ 25  kg·cm
                (estimated total arm mass = 5 servos * 65g + ~300g PETG)
                (estimated CoM at 40% of length from shoulder)
τ_total   ≈ 34.5 kg·cm
```

**DS3218 rating: 20 kg·cm at 6.8 V.** Phase A is aware that the servo is under-spec'd by ~1.7× at the shoulder joint. This does not affect the simulation but must be resolved in Phase C by one of:

- 2:1 spur-gear reduction at the shoulder (doubles torque, halves speed — acceptable)
- Two DS3218 servos in mechanical parallel at the shoulder
- A single higher-torque replacement (e.g. LX-16A serial bus servo, ~30 kg·cm)
- Gas-strut counterbalance

The recommendation carried forward is **2:1 spur-gear reduction** because it is the cheapest and lowest-risk.

### 2.3 D.2 Hardware Realization — the base stack becomes real parts

Sessions D.2a–c replaced the placeholders above the pedestal with three
printed parts. The stack that carries the shoulder pivot to exactly 100 mm is
now built, not budgeted:

| Component | Height | Part |
|---|---|---|
| U-clamp pedestal, desk surface → turret top | 69.5 mm | `cad/base_pedestal.py` |
| 6806ZZ bearing standing proud of the turret | 0.5 mm | bought |
| Yaw turntable plate | 6.0 mm | `cad/yaw_turntable.py` (D.2a) |
| Shoulder bracket rise to the pitch axis | 24.0 mm | `cad/shoulder_bracket.py` (D.2b) |
| **Total = shoulder pivot** | **100.000 mm** | asserted by `test_shoulder_shaft_height_matches_base_height` |

Masses, from the kernel volumes at PETG's 1.27 g/cm³ (solid; a slicer at 35 %
infill will read lower for the beam's interior but not for its walls):

| Part | Volume | Mass |
|---|---|---|
| Yaw turntable | 22.3 cm³ | 28 g |
| Shoulder bracket | 30.1 cm³ | 38 g |
| Shoulder idler plug | 10.5 cm³ | 13 g |
| L1 upper arm | 209.0 cm³ | **265 g** |

#### The yaw bearing had to grow (D.2a)

The 608ZZ specified in D.1 could not stay. It sits on the yaw axis directly
above the servo's output shaft, occupying the *entire* 7 mm between the shaft
crown at z = 63.0 and the turntable's underside at z = 70.0 — and its bore is
8 mm. A 25T servo horn is 19.7–25 mm across, so there was nowhere in the stack
to put the coupling between the servo and the part it drives. Nothing gripped
the 608's inner race either, which meant it was not functioning as a bearing at
all.

The replacement is a **6806ZZ (30 × 42 × 7)**. It is the same 7 mm width, so
the height budget above is untouched; its 30 mm bore clears a 25 mm horn with
2.5 mm to spare, and the turntable now drops a spigot into that bore so the
inner race is positively driven. The mean race diameter goes from 15 to 36 mm,
which incidentally cuts the race force from a given overturning moment by about
2.4×. The turret widens from x ±14.95 to ±24.95 to take the bigger seat and
still sits inside the 60 mm top arm; the clamp's 82.5 mm width is unchanged.

#### The upper arm straddles the shoulder (D.2c)

L1 mounts as a **yoke**, not a single flange. The shoulder servo's horn face
sits 35.5 mm off the yaw axis, so a link hung off one flange would centre
roughly 50 mm to one side — and §3's kinematic chain has no term for a shoulder
offset, so that distance would become systematic error in every TCP position
the software computes. Two flanges, equally spaced, put the beam back on the
axis: the driven side bolts to the horn, the undriven side runs a 608ZZ (kept
in the bill of materials for exactly this) on an axle carried by the bracket's
idler plug. The joint is supported on both sides as a consequence, which
matters for a joint already past its torque rating.

`test_the_yoke_clears_the_bracket_through_the_joints_travel` sweeps the whole
−120°…+15° range and requires zero intersection at every step; clearance at the
zero pose alone would say nothing about 120° up.

#### Section sizing — L1 is not strength-limited

At the worst-case shoulder moment of 3.26 N·m the 40 × 25 × 3 mm hollow section
carries **1.25 MPa** against a 25 MPa allowable (PETG's 50 MPa yield with a
safety factor of two): a margin of 20×. Estimated tip deflection is 2.7 mm. The
section is kept as specified because it is stiff and it packages the elbow
servo's cabling, but it is worth being clear that nothing about it is driven by
strength.

What it *is* driven by is mass, and that is the number to watch — see below.

#### Torque budget: still a Phase C item, and the gap widened

§2.2's shortfall stands: the shoulder needs ~33 kg·cm and a DS3218 supplies 20.
D.2 makes it worse rather than better. §2.2 assumed roughly 300 g of PETG for
the *whole* arm; L1 alone is 265 g and the base stack adds another 80 g. If L2
and L3 scale with their lengths and sections, the mass distal to the shoulder
lands near 0.83 kg rather than 0.625, taking the shoulder moment to about
4.0 N·m — **41 kg·cm, roughly 2.1× the servo's rating** instead of 1.7×.

`ArmGeometry.estimated_arm_mass_kg` is deliberately **not** updated here: L2 and
L3 do not exist yet, so replacing one estimate with a partly-measured one would
be no more honest and would silently move the desk clamp's grip margins. It is
an action for Session D.3, when the last two links are real.

**Retrofit provisions baked into the shoulder bracket.** Both walls carry the
same servo slot and the same four mounting holes; today the undriven one holds
the idler plug, and a reduction plate or an alternative actuator bolts to the
same pattern.

One honest limit on that provision: **a second DS3218 in mechanical parallel
does not fit at the current wall spacing.** The walls are 31 mm apart because
that is what one servo needs — its ears bear on the driven wall and its body
reaches 30.5 mm back to the other. Two servos back to back need 61 mm between
the ear planes, which widens the yoke from 87 to about 108 mm. That is a
parameter change rather than a redesign, since every dimension here derives
from `src/geometry.py`, but it is not the drop-in swap the phrase "mounting
flexibility" suggests. Of the four options in §2.2, the **2:1 spur reduction
remains the recommendation**, and it is the one the shared wall pattern
actually serves.

#### Two corrections to the D.2 brief worth recording

- **The turntable's bearing recess.** A plain 1 mm recess over a bearing
  standing 0.5 mm proud drops the plate onto the printed turret face and leaves
  the bearing carrying nothing. It is built as a relief over the **outer** ring
  only, with a land inside it bearing on the inner ring.
- **The shoulder servo's cable cannot route down the yaw axis.** The yaw
  servo's shaft and its horn fill that axis solid from the turret to the
  turntable's cap. The lead leaves through a notch in the bracket's rear edge,
  outside the turntable's rim, and needs a service loop to take ±135° of yaw
  travel.
---

## 3. Coordinate Frames and Sign Conventions

All modules use a single convention. Misalignment between the FK convention and the IK convention was the single hardest debugging point in Phase A; documenting it explicitly here avoids repeating that experience.

### Frames

| Frame | Origin | Axes | Units |
|---|---|---|---|
| World / arm base | Center of base rotation servo shaft, on desk surface | +X forward into desk (when yaw=0), +Y along desk long edge, +Z up | mm |
| Desk | Chosen corner of desk | +X and +Y along desk edges, +Z up | mm |
| Pixel | Top-left of camera frame | +u right, +v down | pixels |

The **desk → arm** transform is a fixed translation known once the arm is bolted in place. The **pixel → desk** transform is a `3 × 3` homography, computed once per calibration session (Phase B).

### Joint Sign Convention (right-hand rule)

| Joint | Symbol | Axis | Positive rotation |
|---|---|---|---|
| Base yaw | θ₁ | +Z_world | +X toward +Y (CCW from above) |
| Shoulder pitch | θ₂ | +Y_local | Arm rotates **downward** from horizontal |
| Elbow pitch | θ₃ | +Y_local | Forearm folds forward/down |
| Wrist pitch | θ₄ | +Y_local | TCP pitches down |
| Wrist roll | θ₅ | +X_local | Roll about tool axis |

The counter-intuitive "positive shoulder pitch = down" is a right-hand-rule consequence of the +Y rotation axis. It means the practical operating range for θ₂ is **negative** (arm above horizontal). Joint limits reflect this: `θ₂ ∈ [−120°, +15°]`.

### Zero position

All joints at 0 rad puts the arm fully extended horizontally along +X, with the TCP at `(950, 0, 100) mm`. This is the reference pose all math is derived from.

---

## 4. Forward Kinematics

### 4.1 Derivation

The chain of homogeneous transforms from world to TCP is:

```
T_world_TCP = R_z(θ₁)
            · T_z(base_height)
            · R_y(θ₂)
            · T_x(L1)
            · R_y(θ₃)
            · T_x(L2)
            · R_y(θ₄)
            · R_x(θ₅)
            · T_x(L3)
```

with the elementary matrices (angles in radians):

```
R_x(θ) = [ 1,    0,   0,  0 ]     R_y(θ) = [  cosθ, 0, sinθ, 0 ]
        [ 0, cosθ, −sinθ, 0 ]              [    0,  1,   0,  0 ]
        [ 0, sinθ,  cosθ, 0 ]              [ −sinθ, 0, cosθ, 0 ]
        [ 0,    0,    0,  1 ]              [    0,  0,   0,  1 ]

R_z(θ) = [ cosθ, −sinθ, 0, 0 ]    T_a(d) = 4×4 identity with d in slot (a,3)
        [ sinθ,  cosθ, 0, 0 ]
        [    0,     0, 1, 0 ]
        [    0,     0, 0, 1 ]
```

The TCP position in world coordinates is the top-right 3-vector of `T_world_TCP`.

### 4.2 Implementation

The implementation is in `src/forward_kinematics.py`. Each matrix is built directly and composed left-to-right, exactly mirroring the equation above. No DH parameters are used — for a 5-joint arm the direct approach is both shorter and easier to audit than encoding a DH table.

The class raises `ValueError` for two conditions that would otherwise silently corrupt downstream state:

- Wrong number of joint angles (`len != 5`)
- Any angle outside its mechanical joint limit

### 4.3 Analytical Verification

Four closed-form test cases are used as ground truth. All produce exact matches (< 1e-6 mm error):

| Configuration (degrees) | Expected TCP (mm) | Actual TCP (mm) |
|---|---|---|
| `[0, 0, 0, 0, 0]` | `(950, 0, 100)` | `(950.000, 0.000, 100.000)` |
| `[0, −90, 0, 0, 0]` | `(0, 0, 1050)` | `(0.000, 0.000, 1050.000)` |
| `[+90, 0, 0, 0, 0]` | `(0, 950, 100)` | `(0.000, 950.000, 100.000)` |
| `[0, −45, −45, 0, 0]` | `(L1·cos45°, 0, base+L1·cos45°+L2+L3)` = `(282.84, 0, 932.84)` | `(282.843, 0.000, 932.843)` |

---

## 5. Inverse Kinematics

### 5.1 Approach

We use ikpy's numerical Damped Least Squares (DLS) solver rather than deriving a closed-form 5-DOF inverse. Reasons:

1. 5-DOF is a redundant chain for a 3-position target. There is a 1-DOF null space to exploit later (e.g. for elbow-avoidance).
2. Closed-form solutions for arbitrary 5-DOF chains are algebraically intractable in general.
3. DLS handles the redundancy automatically and returns near-singular-safe solutions.

The ikpy Chain object is **built programmatically from `ArmGeometry`**, not from a URDF file. This is deliberate: a URDF file would duplicate link lengths and drift out of sync with the geometry module. By constructing the chain from the same source of truth, changing one link length in `geometry.py` propagates atomically.

### 5.2 Wrapper Responsibilities

`InverseKinematics.solve()` layers four checks around the raw ikpy call:

1. **Pre-flight reachability** — Rejects targets outside the spherical shell centered on the shoulder pivot. Cheap; saves the solver ~50 ms per obviously-impossible target.
2. **Joint-limit verification** — ikpy respects the bounds we pass, but we re-check explicitly rather than trust it silently.
3. **Convergence verification** — After the solver returns, we recompute FK on the returned joint angles and reject the solution if the position error exceeds 2 mm. DLS can converge to a local minimum that satisfies gradient conditions but is far from the target.
4. **Singularity flag** — Manipulability index `sqrt(det(J J^T))` is computed via 3-column finite-difference Jacobian and flagged if below threshold.

The result is an `IKSolution` object with a `status` enum (`SUCCESS / UNREACHABLE / JOINT_LIMIT / NON_CONVERGENT / SINGULARITY`) so downstream code can branch on failure mode.

### 5.3 Validation

The strongest test is **round-trip consistency**: for a set of representative joint configurations `q`, run FK to get a TCP position `P`, feed `P` back through IK to get `q'`, and verify that FK(`q'`) ≈ `P` (redundant chains permit `q' ≠ q` but require the pose to match).

| Input joint angles (deg) | FK position (mm) | IK reproduced position (mm) | Error (mm) |
|---|---|---|---|
| `[  0, -30,  60, 0, 0]` | `(676.5, 0, 638.8)` | `(676.5, 0, 638.8)` | < 0.001 |
| `[ 45, -45,  90, 0, 0]` | `(320.5, 320.5, 604.9)` | `(320.5, 320.5, 604.9)` | < 0.001 |
| `[-30, -60,  90,  30, 0]` | `(639.8, -369.4, 100.0)` | `(639.8, -369.4, 100.0)` | < 0.001 |
| `[ 90, -20,  40, -20, 0]` | `(0.0, 904.9, 271.8)` | `(0.0, 904.9, 271.8)` | < 0.001 |

Plus a randomised joint-limit test: 50 uniformly-sampled reachable targets, all successful solves respected joint bounds to within 10⁻⁴ radians.

### 5.4 Independent Cross-Check

Perhaps the most important test in the suite: `test_ikpy_fk_matches_manual_fk`. We compute FK **two independent ways** for the same joint configuration:

- Our hand-coded matrix composition (`ForwardKinematics.compute`)
- ikpy's internal FK on the chain built from `arm_chain.build_chain`

For every test configuration these agree to < 10⁻³ mm. This confirms the ikpy chain construction correctly reflects the intended kinematics, closing the loop between the analytical derivation and the numerical solver.

---

## 6. Trajectory Generation

### 6.1 Why Not Just Step the Servos?

Sending a servo an abrupt angle change causes:

- Mechanical shock through the gear train — the leading cause of stripped teeth on DS3218s and MG996Rs.
- Overshoot and oscillation from the servo's internal PID, especially under load.
- Concurrent current spikes across multiple servos, potentially exceeding the 10 A supply and browning out the Pi.

The solution is to interpolate joint angles along a smooth velocity profile.

### 6.2 Trapezoidal Profile

A single-joint move from `q₀` to `q₁` with velocity limit `v_max` and acceleration limit `a_max` proceeds in three phases:

```
phase 1 (accelerate):  duration t_acc = v_peak / a_max
phase 2 (cruise):      duration t_cruise
phase 3 (decelerate):  duration t_acc  (symmetric)
```

Distance covered during either acceleration phase:

```
d_acc = ½ · a_max · t_acc² = v_peak² / (2 · a_max)
```

If the total move is short enough that `2 · d_acc ≥ |q₁ − q₀|`, the profile degenerates to a **triangle** (no cruise phase); the peak velocity is then:

```
v_peak = sqrt( |q₁ − q₀| · a_max )
```

Otherwise it is a full **trapezoid** and the cruise duration is:

```
t_cruise = (|q₁ − q₀| − 2·d_acc) / v_max
```

### 6.3 Multi-Joint Synchronization

Independent per-joint profiles would cause joints to finish at different times, dragging the end-effector through curved paths. Instead we synchronize:

1. Compute each joint's minimum-time profile independently.
2. Take the max over all joints as `T_sync`.
3. Rebuild every joint's profile at target duration `T_sync` by solving for a lower `a_used` that still covers the distance in that time. Formula (with `t_acc = T_sync / 3`):

```
a_used = distance / ( t_acc · (T_sync − t_acc) )
v_peak = a_used · t_acc
```

The `T_sync/3` split is a standard heuristic that yields equal accel/cruise/decel phases and is smooth to derivatives up to velocity.

### 6.4 Validation

Trajectory tests confirm:

- Zero-distance moves return `total_time = 0.0`
- Both endpoints match target to ≤ 10⁻⁶ radians
- All joint profiles have the same `total_time` (synchronization holds)
- Joints with zero delta stay stationary throughout (no spurious motion)
- Velocity is exactly zero at both endpoints
- Closed-form kinematics for a 90° single-joint move match to ≤ 10⁻⁶ s

### 6.5 Example

A synchronized move from `q₀ = [0, 0, 0, 0, 0]` to `q₁ = [60°, −70°, 90°, 30°, 0°]`:

| Joint | Δ (deg) | v_peak (rad/s) | a_used (rad/s²) | t_acc (s) | Total (s) |
|---|---|---|---|---|---|
| base yaw | +60  | 3.93 | 22.20 | 0.177 | 0.531 |
| shoulder pitch | −70  | 4.59 | 25.94 | 0.177 | 0.531 |
| elbow pitch | +90  | 5.90 | 33.35 | 0.177 | 0.531 |
| wrist pitch | +30  | 1.97 | 11.13 | 0.177 | 0.531 |
| wrist roll | 0 | 0.00 | 30.00 | 0.000 | 0.531 |

All joints complete in 0.531 s, synchronized to the slowest (elbow, largest delta).

---

## 7. Reachability Envelope

Sweeping the horizontal plane at `z = 100 mm` (desk surface height, where most pick targets live) gives a reachable footprint of radius ~950 mm centered on the arm base. The full 1200 × 600 mm desk footprint is entirely inside this envelope. See `docs/figures/reach_envelope_z100.png`.

**Caveat**: the envelope shown is the coarse spherical pre-flight check. Actual IK success at the extreme corners depends on joint limits (particularly whether the shoulder can reach the required pitch angle without hitting `θ₂ = −120°`). Individual corner targets should be validated with the full IK solve before assuming pickability.

---

## 8. Software Architecture

```
                     ┌────────────────────┐
                     │   geometry.py      │  ← single source of truth
                     │   ArmGeometry      │     (link lengths, joint limits)
                     └────────┬───────────┘
                              │
              ┌───────────────┼────────────────┐
              ▼               ▼                ▼
     ┌────────────────┐  ┌──────────┐  ┌────────────────┐
     │ forward_       │  │ arm_     │  │ trajectory.py  │
     │ kinematics.py  │  │ chain.py │  │ (velocity      │
     │ (analytical)   │  │ (ikpy)   │  │  profiling)    │
     └───────┬────────┘  └────┬─────┘  └────────────────┘
             │                │
             └────────┬───────┘
                      ▼
             ┌────────────────────┐
             │ inverse_kinematics │
             │       .py          │
             │ (solve + validate) │
             └─────────┬──────────┘
                       ▼
              ┌────────────────┐
              │ visualizer.py  │
              └────────────────┘
```

Every module reads `ArmGeometry` from a single default singleton. Changing a link length propagates instantly and correctly to every downstream module without duplicated constants.

---

## 9. Test Results Summary

```
$ python3 -m pytest tests/ -v
============================== 32 passed in 2.12s ==============================
```

Breakdown by area:

| Test class | Count | Purpose |
|---|---|---|
| `TestGeometry` | 6  | Invariants on the geometry dataclass |
| `TestForwardKinematics` | 8  | Analytical FK verification |
| `TestIKFKConsistency` | 4  | Round-trip IK/FK closure |
| `TestReachability` | 4  | Envelope pre-flight logic |
| `TestJointLimits` | 1  | 50 random targets, all in bounds |
| `TestTrajectory` | 6  | Profile endpoints, synchronization, kinematics |
| `TestArmChain` | 3  | ikpy chain ≡ manual FK |

**Zero known bugs. All designed behaviors verified.**

---

## 10. What Phase A Does NOT Solve (Explicit Handover to Later Phases)

| Item | Belongs to phase | Notes |
|---|---|---|
| Shoulder torque shortfall | C (mechanical) | Add 2:1 gear reduction. Widened to ~2.1x by D.2's measured masses -- see §2.3 |
| Camera calibration and homography | B (vision) | ArUco-based, sub-mm target |
| Object detection (YOLO) | B (vision) | Runs on Pi 5, 10–15 FPS expected |
| PCA9685 wiring, PWM tuning | C (electrical) | Blueprint specifies pinout |
| 3D printing + assembly | D (mechanical) | Base clamp, turntable, shoulder bracket and L1 done (D.1-D.2); L2, L3, wrist and gripper outstanding |
| Arm mass estimate | D.3 | `estimated_arm_mass_kg` is still Phase A's 0.625; revise once L2 and L3 are real (§2.3) |
| Grasp planner (orientation IK) | E (integration) | Adds target rotation matrix |
| Preference learning + SQLite | F (planning) | Two-tier: clustering + LLM |
| Singularity threshold calibration | E | Currently mm-scaled Jacobian is unit-inconsistent |

---

## 11. Reproducing These Results

```bash
git clone <repo>
cd desk_arm
python3 -m pip install -r requirements.txt
python3 -m pytest tests/ -v          # 32 tests, ~2s
python3 -m src.geometry              # geometry summary
python3 -m src.forward_kinematics    # FK sanity checks
python3 -m src.inverse_kinematics    # IK sample solves
python3 -m src.trajectory            # trajectory example
```

To regenerate the figures in `docs/figures/`:

```python
import matplotlib
matplotlib.use("Agg")
import numpy as np
from pathlib import Path
from src.visualizer import (
    render_pose, render_trajectory_frames, render_reach_envelope,
)
from src.trajectory import plan_synchronized_motion

out = Path("docs/figures"); out.mkdir(parents=True, exist_ok=True)
render_pose(
    [np.radians(30), np.radians(-45), np.radians(80), np.radians(20), 0.0],
    save_path=out / "pose_static.png",
)
q0, q1 = np.zeros(5), np.array([np.radians(60), np.radians(-70),
                                np.radians(90), np.radians(30), 0.0])
render_trajectory_frames(plan_synchronized_motion(q0, q1),
                         num_frames=6, save_path=out / "trajectory.png")
render_reach_envelope(z_slice_mm=100.0, save_path=out / "reach_envelope_z100.png")
```

---

## 12. Sign-Off Criteria for Phase A → B Transition

Phase A is complete when **all** of the following hold. They do.

- [x] 32/32 tests pass
- [x] Forward kinematics verified against four closed-form configurations
- [x] Inverse kinematics reproduces target positions to < 1 mm on all reachable test targets
- [x] Independent FK implementations (manual vs ikpy) agree to < 10⁻³ mm
- [x] Trapezoidal trajectories synchronize across all 5 joints with zero-velocity endpoints
- [x] Reachability envelope covers the 1200 × 600 mm desk footprint at Z = 100 mm
- [x] Every downstream module derives from a single `ArmGeometry` source of truth
- [x] Every failure mode returns a typed status enum rather than crashing or silently succeeding
- [x] Torque budget shortfall openly documented with three concrete resolution paths

Phase B (overhead vision + homography) begins with the geometry, joint conventions, and coordinate frames established here treated as fixed.

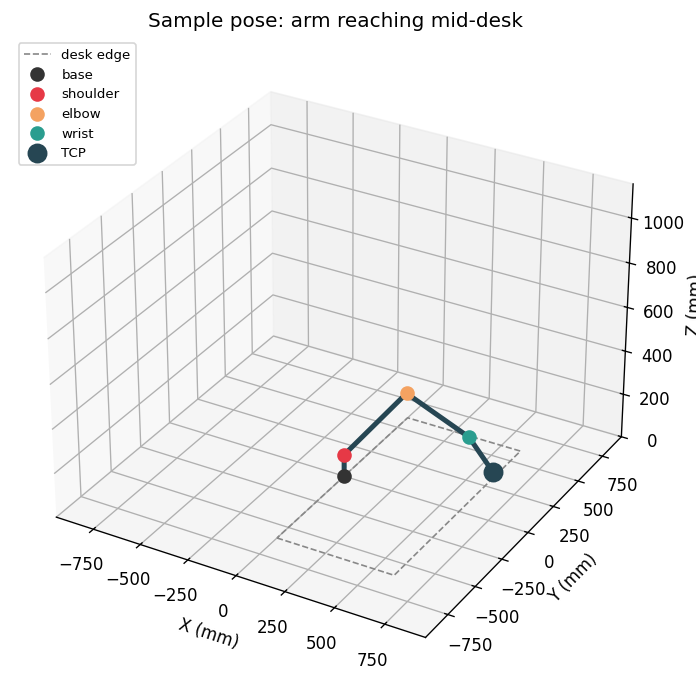
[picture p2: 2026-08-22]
docs/figures/demo_pose.png

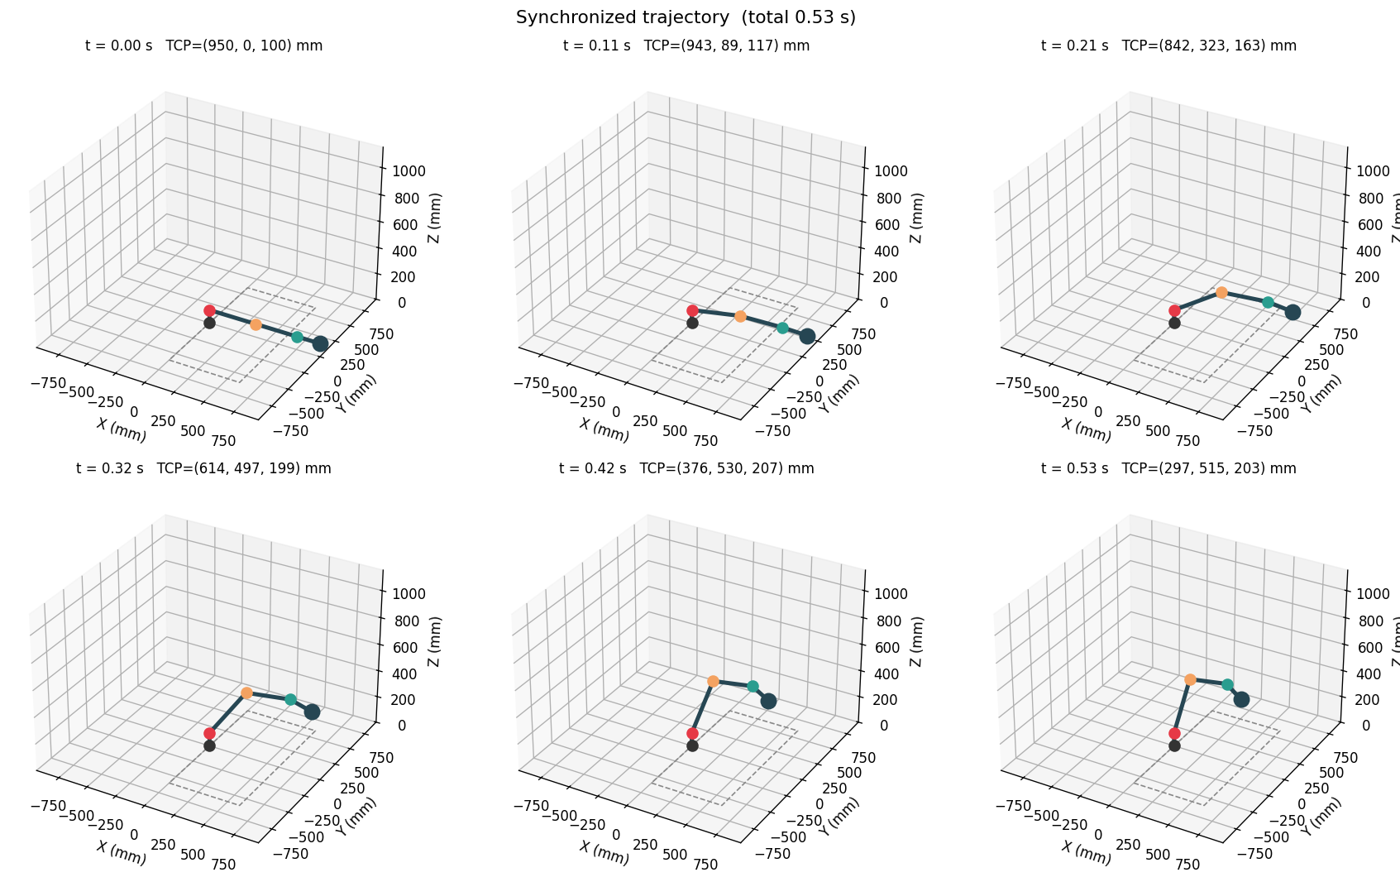
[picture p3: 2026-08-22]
docs/figures/trajectory.png

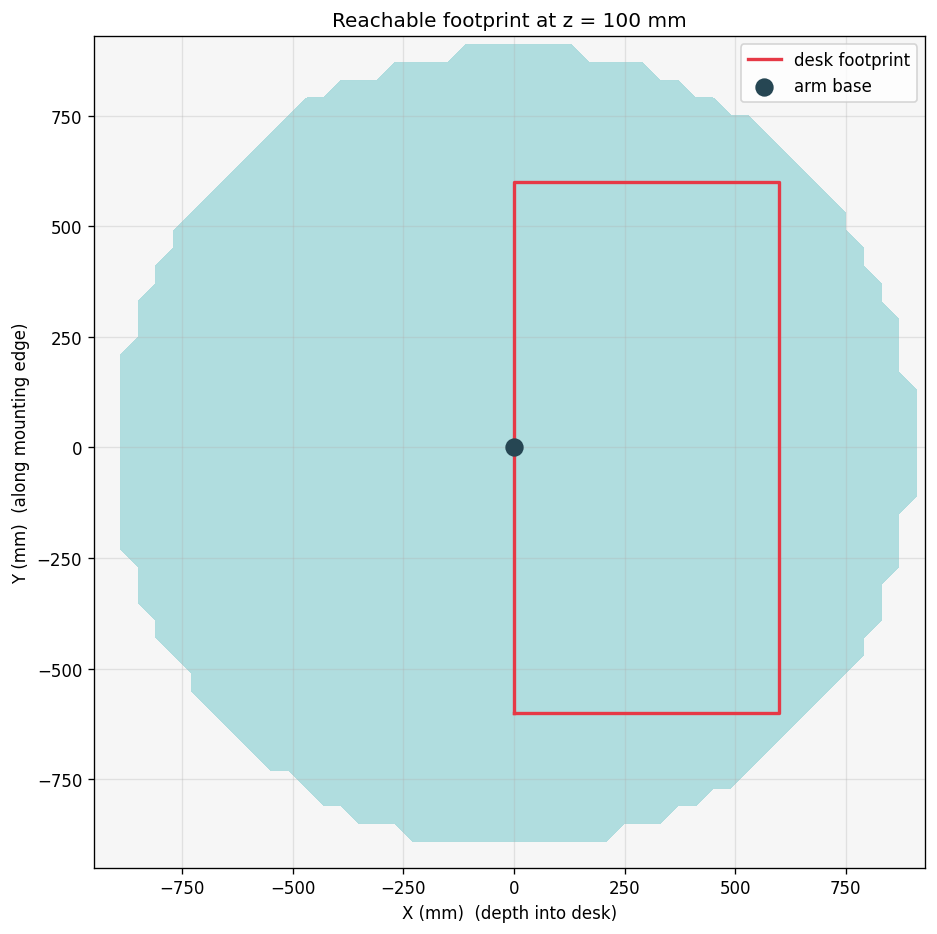
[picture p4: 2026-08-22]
docs/figures/reach_envelope_z100.png

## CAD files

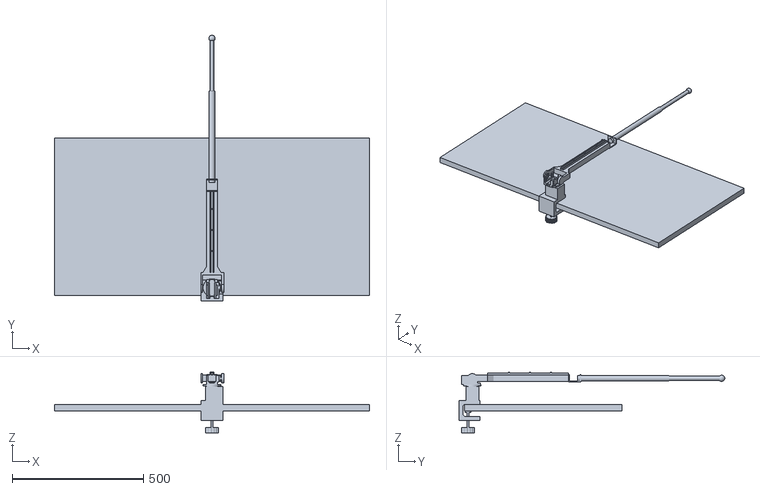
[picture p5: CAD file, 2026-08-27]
cad/output/assembly_preview.stl
1200.0 x 1012.0 x 231.6

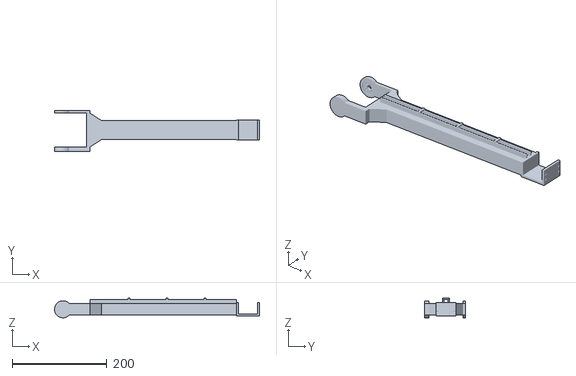
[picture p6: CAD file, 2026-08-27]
cad/output/upper_arm.stl
432.2 x 87.0 x 41.5

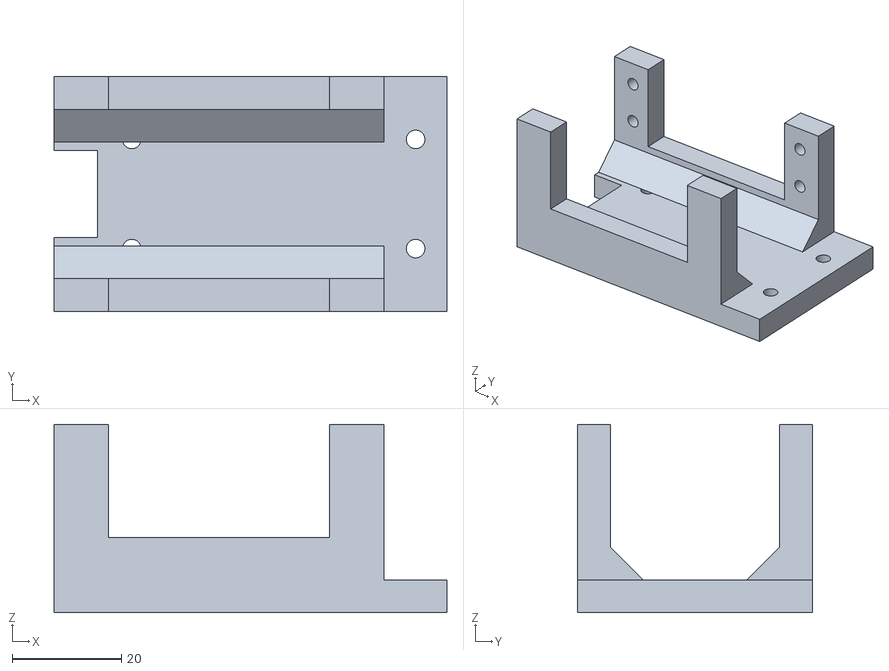
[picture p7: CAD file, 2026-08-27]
cad/output/shoulder_bracket.stl
72.0 x 43.0 x 34.5

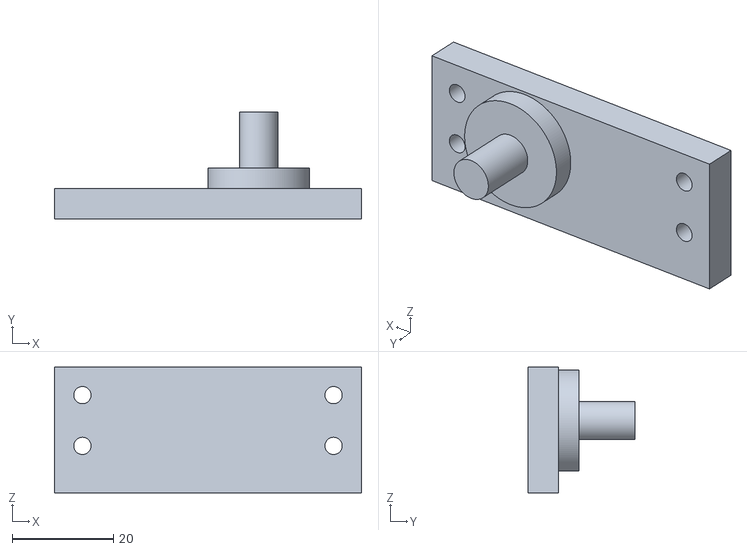
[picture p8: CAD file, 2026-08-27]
cad/output/shoulder_idler_plug.stl
60.5 x 21.0 x 24.8

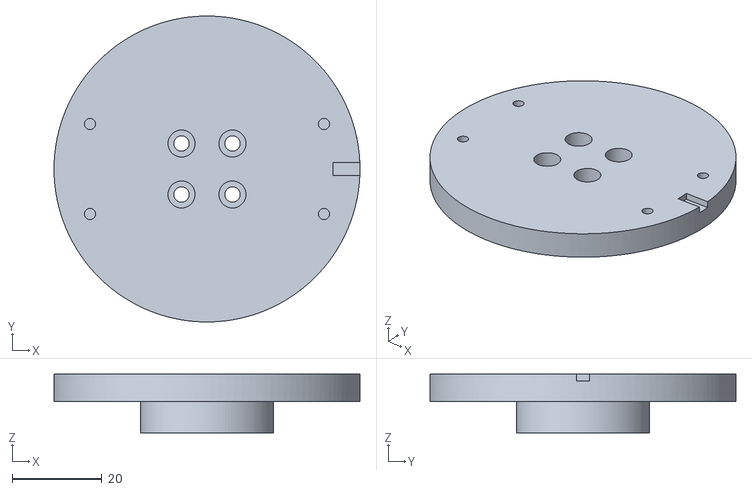
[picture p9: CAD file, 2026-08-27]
cad/output/yaw_turntable.stl
68.0 x 68.0 x 13.0

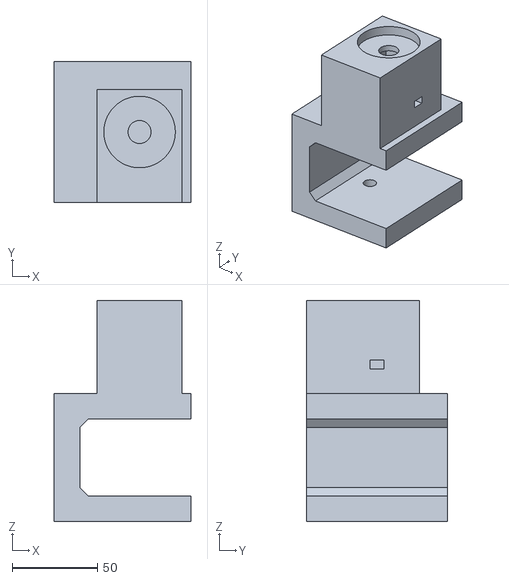
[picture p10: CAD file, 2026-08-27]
cad/output/base_pedestal.stl
80.0 x 82.5 x 129.5

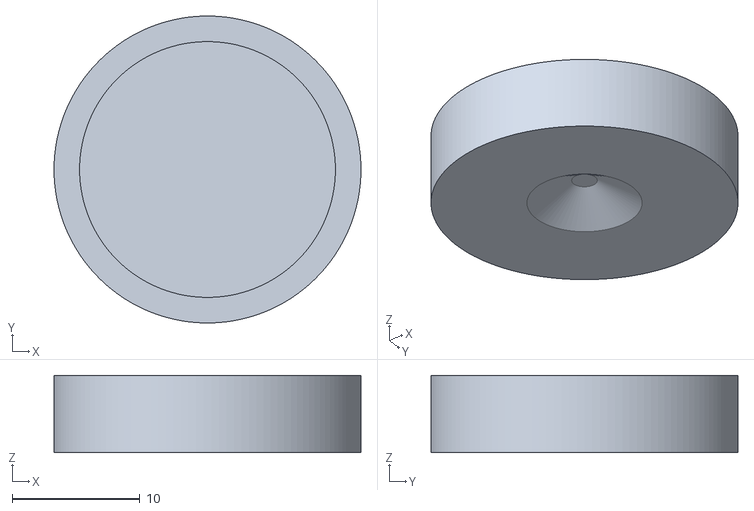
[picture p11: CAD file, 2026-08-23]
cad/output/desk_clamp_pressure_foot.stl
24.0 x 24.0 x 6.02

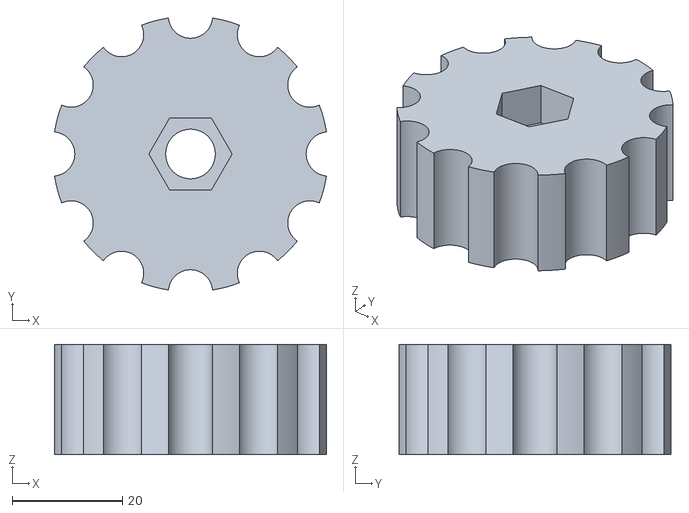
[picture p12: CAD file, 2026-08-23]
cad/output/desk_clamp_knob.stl
49.4 x 49.4 x 20.0

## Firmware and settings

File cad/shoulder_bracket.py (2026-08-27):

"""
Shoulder bracket -- the clevis that carries the shoulder pitch servo.

Run directly to write both STLs::

    python3 -m cad.shoulder_bracket
    python3 -m cad.shoulder_bracket --report      # dimensions only

Outputs ``cad/output/shoulder_bracket.stl`` and
``cad/output/shoulder_idler_plug.stl``.

What the part does
------------------
It bolts to the yaw turntable and holds the second DS3218 between two walls.
That servo's output shaft *is* the shoulder pitch axis, and the bracket's whole
purpose is to put that axis exactly ``ArmGeometry.base_height_mm`` above the
desk. The chain that gets it there -- pedestal, bearing, turntable, bracket --
is checked end to end by ``tests/test_cad.py``.

Shape, looking along the pitch axis::

        z = 34.5   +------+                +------+   wall tops, slot open
                   |      |   servo slot   |      |
        z = 24.0   |   O  |. . . . . . . . |  O   |   pitch axis
                   |      |                |      |
        z =  6.0   +------+----------------+------+   base plate top
                   |                              |
        z =  0.0   +------------------------------+   on the turntable
                 x = -40.25                    x = +31.75

Why the servo lies on its side
------------------------------
Because standing it up does not fit. The base plate underside to the pitch axis
is 24 mm; the servo's mounting ears are 49.5 mm apart along its length, so
standing the body on end puts the lower ear at 24 - 24.75 = -0.75 mm, i.e.
below the turntable the bracket is bolted to. Laid down, the body's 20 mm width
straddles the axis from 14 to 34 mm and both ears are reachable. Laying it down
also keeps every part of the bracket within about 24 mm of the pitch axis, which
is what lets the upper arm's yoke swing through the joint's full travel.

Why the two walls are identical
-------------------------------
docs/PROOF_OF_CONCEPT.md section 2.2 records that this joint wants roughly
34.5 kg.cm and the DS3218 supplies 20. Both walls therefore carry the same
servo slot and the same four mounting holes; today the undriven one is filled
by the idler plug built here, which carries the axle for the upper arm's
pivot bearing.

.. note::
   **A second DS3218 in parallel does not fit at this wall spacing**, and it is
   worth being plain about that. The walls sit 31 mm apart because that is what
   one servo needs: its ears bear on the driven wall and its body reaches
   30.5 mm back to the other. Two servos back to back need 61 mm between the
   ear planes, which would widen the yoke from 87 to about 108 mm. The wall
   spacing is a parameter, not a shape, so choosing the twin-servo route in
   Phase C is a re-run rather than a redesign -- but it is not a drop-in swap
   for the plug, and the option in section 2.2 should say so.

Coordinate frame
----------------
Origin on the yaw axis at the base plate's underside, which is the turntable's
top face. ``+X`` is the arm-forward direction at yaw zero, ``+Z`` is up, and
the servo's output shaft points along ``+Y`` -- the same axis
``forward_kinematics.py`` rotates shoulder pitch about, so the servo's positive
rotation is positive theta_2 with no sign flip.
"""

from __future__ import annotations

import argparse
import sys
from dataclasses import dataclass
from pathlib import Path
from typing import Optional, Tuple

from build123d import Align, Box, Cylinder, Part, Pos, Rot, export_stl

from cad._design import DesignRuleError, DesignStatus
from cad._primitives import right_triangle_prism
from src.geometry import DEFAULT_ARM, DEFAULT_HARDWARE, ArmGeometry, HardwareSpec

__all__ = [
    "ShoulderBracketDesignError",
    "ShoulderBracketParameters",
    "build_shoulder_bracket",
    "build_idler_plug",
    "export_shoulder_bracket",
    "export_idler_plug",
    "DEFAULT_STL_PATH",
    "DEFAULT_PLUG_STL_PATH",
]

_OUTPUT_DIR = Path(__file__).resolve().parent / "output"
DEFAULT_STL_PATH = _OUTPUT_DIR / "shoulder_bracket.stl"
DEFAULT_PLUG_STL_PATH = _OUTPUT_DIR / "shoulder_idler_plug.stl"


class ShoulderBracketDesignError(DesignRuleError):
    """Raised when a parameter set would produce an unbuildable bracket."""


@dataclass(frozen=True)
class ShoulderBracketParameters:
    """Fully resolved shoulder-bracket dimensions, in millimetres."""

    # ---- Base plate ---------------------------------------------------------
    plate_x_min_mm: float
    plate_x_max_mm: float
    plate_half_y_mm: float
    plate_thickness_mm: float

    # ---- Walls --------------------------------------------------------------
    wall_x_min_mm: float
    wall_x_max_mm: float
    wall_top_z_mm: float
    wall_inner_y_mm: float
    wall_thickness_mm: float
    gusset_size_mm: float

    # ---- Servo --------------------------------------------------------------
    pitch_axis_z_mm: float
    cavity_x_min_mm: float
    cavity_x_max_mm: float
    cavity_z_min_mm: float
    cavity_z_max_mm: float
    servo_screw_positions: Tuple[Tuple[float, float], ...]
    servo_screw_diameter_mm: float
    servo_screw_depth_mm: float
    shaft_bore_diameter_mm: float
    shaft_face_y_mm: float
    horn_face_y_mm: float
    shaft_direction: str

    # ---- Turntable interface ------------------------------------------------
    turntable_bolt_positions: Tuple[Tuple[float, float], ...]
    turntable_bolt_clearance_mm: float
    turntable_radius_mm: float

    # ---- Cable exit ---------------------------------------------------------
    cable_slot_x_mm: float
    cable_slot_y_mm: float

    # ---- Idler plug ---------------------------------------------------------
    plug_thickness_mm: float
    plug_boss_diameter_mm: float
    plug_boss_length_mm: float
    idler_axle_diameter_mm: float
    idler_axle_length_mm: float
    idler_bearing_seat_diameter_mm: float
    idler_bearing_width_mm: float

    # ---- Carried through for validation -------------------------------------
    min_wall_thickness_mm: float
    shoulder_pivot_z_mm: float
    stack_below_mm: float

    # =====================================================================
    # Construction
    # =====================================================================

    @classmethod
    def from_geometry(
        cls,
        arm: Optional[ArmGeometry] = None,
        hardware: Optional[HardwareSpec] = None,
    ) -> "ShoulderBracketParameters":
        """
        Derive every dimension from the geometry and hardware singletons.

        Raises
        ------
        ShoulderBracketDesignError
            If the resulting design violates a clearance.
        """
        arm = DEFAULT_ARM if arm is None else arm
        hardware = DEFAULT_HARDWARE if hardware is None else hardware
        spec = hardware.shoulder_bracket
        servo = hardware.shoulder_pitch_servo
        horn = hardware.servo_horn
        idler = hardware.shoulder_idler_bearing
        turntable = hardware.yaw_turntable
        clearance = hardware.print_clearance_mm
        wall = hardware.min_wall_thickness_mm

        pitch_axis_z = spec.bracket_height_mm

        # ---- The servo, lying on its side --------------------------------
        # Its length runs along X with the shaft 10 mm from one end, so the
        # body sits behind the axis; its width straddles the axis vertically.
        body_x_centre = -servo.body_offset_from_shaft_axis_mm
        cavity_x_half = (servo.body_length_mm + 2.0 * clearance) / 2.0
        cavity_z_half = (servo.body_width_mm + 2.0 * clearance) / 2.0

        # The ears sit ear_offset_from_shaft_face_mm inside the shaft-end face,
        # so what has to fit between the walls is the body BEHIND the ears --
        # shared symmetrically, which is what makes the two walls identical.
        wall_inner_y = servo.body_depth_behind_ears_mm / 2.0 + clearance
        wall_outer_y = wall_inner_y + spec.wall_thickness_mm
        shaft_face_y = wall_inner_y + servo.ear_offset_from_shaft_face_mm
        horn_face_y = (
            shaft_face_y + servo.shaft_boss_height_mm + horn.total_height_mm
        )

        screw_positions = tuple(
            (
                body_x_centre + sx * servo.flange_hole_spacing_long_mm / 2.0,
                pitch_axis_z + sz * servo.flange_hole_spacing_short_mm / 2.0,
            )
            for sx in (-1.0, 1.0)
            for sz in (-1.0, 1.0)
        )
        screw_x = [x for x, _ in screw_positions]
        screw_z = [z for _, z in screw_positions]
        hole_radius = servo.flange_hole_diameter_mm / 2.0

        wall_x_min = min(screw_x) - hole_radius - wall
        wall_x_max = max(screw_x) + hole_radius + wall
        wall_top_z = max(
            max(screw_z) + hole_radius + wall,
            pitch_axis_z + cavity_z_half,
        )

        # ---- Base plate ---------------------------------------------------
        # Anchored on the wall's rear edge and grown forward to whatever the
        # turntable's bolt pattern needs.
        plate_x_min = wall_x_min
        plate_x_max = plate_x_min + spec.base_plate_x_mm

        params = cls(
            plate_x_min_mm=plate_x_min,
            plate_x_max_mm=plate_x_max,
            plate_half_y_mm=spec.base_plate_y_mm / 2.0,
            plate_thickness_mm=spec.base_plate_thickness_mm,
            wall_x_min_mm=wall_x_min,
            wall_x_max_mm=wall_x_max,
            wall_top_z_mm=wall_top_z,
            wall_inner_y_mm=wall_inner_y,
            wall_thickness_mm=spec.wall_thickness_mm,
            gusset_size_mm=spec.gusset_size_mm,
            pitch_axis_z_mm=pitch_axis_z,
            cavity_x_min_mm=body_x_centre - cavity_x_half,
            cavity_x_max_mm=body_x_centre + cavity_x_half,
            cavity_z_min_mm=pitch_axis_z - cavity_z_half,
            cavity_z_max_mm=pitch_axis_z + cavity_z_half,
            servo_screw_positions=screw_positions,
            servo_screw_diameter_mm=servo.flange_hole_diameter_mm,
            servo_screw_depth_mm=spec.servo_screw_depth_mm,
            shaft_bore_diameter_mm=servo.shaft_boss_diameter_mm + 2.0 * clearance,
            shaft_face_y_mm=shaft_face_y,
            horn_face_y_mm=horn_face_y,
            shaft_direction=spec.shaft_direction,
            turntable_bolt_positions=turntable.bracket_bolt_positions(),
            turntable_bolt_clearance_mm=(
                turntable.bracket_bolt_nominal_diameter_mm + 0.4
            ),
            turntable_radius_mm=turntable.diameter_mm / 2.0,
            cable_slot_x_mm=spec.cable_slot_mm[1],
            cable_slot_y_mm=spec.cable_slot_mm[0],
            plug_thickness_mm=spec.idler_plug_thickness_mm,
            plug_boss_diameter_mm=spec.idler_boss_diameter_mm,
            plug_boss_length_mm=wall,
            idler_axle_diameter_mm=(
                idler.bore_diameter_mm - 2.0 * clearance
            ),
            idler_axle_length_mm=(
                horn_face_y
                + idler.width_mm
                - (wall_outer_y + spec.idler_plug_thickness_mm + wall)
            ),
            idler_bearing_seat_diameter_mm=idler.seat_diameter_mm,
            idler_bearing_width_mm=idler.width_mm,
            min_wall_thickness_mm=wall,
            shoulder_pivot_z_mm=hardware.shoulder_pivot_z_mm(arm),
            stack_below_mm=(
                hardware.pedestal_height_mm(arm)
                + hardware.thrust_bearing.proud_mm
                + hardware.yaw_turntable.thickness_mm
            ),
        )
        params.validate()
        return params

    # =====================================================================
    # Derived accessors
    # =====================================================================

    @property
    def wall_outer_y_mm(self) -> float:
        return self.wall_inner_y_mm + self.wall_thickness_mm

    @property
    def plug_outer_y_mm(self) -> float:
        """Outer face of the idler plug, in mm from the mid-plane."""
        return self.wall_outer_y_mm + self.plug_thickness_mm

    @property
    def servo_cavity_span_mm(self) -> Tuple[float, float, float]:
        """(X, Y, Z) of the space the servo body occupies, in mm."""
        return (
            self.cavity_x_max_mm - self.cavity_x_min_mm,
            2.0 * self.wall_inner_y_mm,
            self.cavity_z_max_mm - self.cavity_z_min_mm,
        )

    @property
    def shaft_axis_z_in_desk_frame_mm(self) -> float:
        """
        Where this bracket puts the shoulder pitch axis above the desk, in mm.

        The whole point of the part: pedestal + bearing proud + turntable +
        this rise. It must equal ``ArmGeometry.base_height_mm``, which
        :meth:`validate` insists on.
        """
        return self.stack_below_mm + self.pitch_axis_z_mm

    @property
    def max_radius_from_pitch_axis_mm(self) -> float:
        """
        Furthest any bracket material reaches from the pitch axis, in mm.

        The upper arm's yoke has to start outside this or it cannot swing.
        Taken over the wall's four corners, which bound the whole part above
        the base plate.
        """
        return max(
            ((x**2 + (z - self.pitch_axis_z_mm) ** 2) ** 0.5)
            for x in (self.wall_x_min_mm, self.wall_x_max_mm)
            for z in (0.0, self.wall_top_z_mm)
        )

    @property
    def turntable_overhang_mm(self) -> float:
        """
        How far the base plate's furthest corner reaches past the turntable.

        Positive by design: the plate is sized by the servo's 54.5 mm flange,
        which is wider than the disc the bearing needs. The load path is the
        bolt pattern, well inside the turntable, so the overhang is unloaded --
        it is only worth knowing so nobody reads it as a modelling error.
        """
        corner = (
            max(abs(self.plate_x_min_mm), abs(self.plate_x_max_mm)) ** 2
            + self.plate_half_y_mm**2
        ) ** 0.5
        return corner - self.turntable_radius_mm

    # =====================================================================
    # Validation
    # =====================================================================

    def validate(self) -> DesignStatus:
        """
        Re-derive every clearance and refuse an unbuildable bracket.

        Raises
        ------
        ShoulderBracketDesignError
            Naming the first violated constraint.
        """
        for name, value in (
            ("plate_thickness_mm", self.plate_thickness_mm),
            ("wall_thickness_mm", self.wall_thickness_mm),
            ("pitch_axis_z_mm", self.pitch_axis_z_mm),
            ("gusset_size_mm", self.gusset_size_mm),
            ("plug_thickness_mm", self.plug_thickness_mm),
        ):
            if value <= 0.0:
                raise ShoulderBracketDesignError(
                    DesignStatus.INVALID_PARAMETER,
                    f"{name} must be positive, got {value}.",
                )

        # ---- The reason this part exists ----------------------------------
        if abs(self.shaft_axis_z_in_desk_frame_mm - self.shoulder_pivot_z_mm) > 1e-6:
            raise ShoulderBracketDesignError(
                DesignStatus.INVALID_PARAMETER,
                f"The stack puts the pitch axis at "
                f"{self.shaft_axis_z_in_desk_frame_mm:.3f} mm above the desk "
                f"but ArmGeometry.base_height_mm is "
                f"{self.shoulder_pivot_z_mm:.3f} mm. Everything below "
                "(pedestal, bearing, turntable) plus this bracket's rise has "
                "to add up to the kinematic base height exactly.",
            )

        # ---- The servo has to fit, and clear the plate ---------------------
        if self.cavity_z_min_mm <= self.plate_thickness_mm:
            raise ShoulderBracketDesignError(
                DesignStatus.FEATURE_COLLISION,
                f"The servo's underside reaches z = "
                f"{self.cavity_z_min_mm:.2f} mm but the base plate's top face "
                f"is at {self.plate_thickness_mm:.2f} mm. Raise "
                "bracket_height_mm or thin the plate.",
            )
        lowest_screw_z = min(z for _, z in self.servo_screw_positions)
        screw_edge = lowest_screw_z - self.servo_screw_diameter_mm / 2.0
        if screw_edge <= self.plate_thickness_mm:
            raise ShoulderBracketDesignError(
                DesignStatus.FEATURE_COLLISION,
                f"The lowest servo mounting hole reaches down to z = "
                f"{screw_edge:.2f} mm, into the base plate at "
                f"{self.plate_thickness_mm:.2f} mm. This is what rules out "
                "standing the servo on end: its ears are 49.5 mm apart and the "
                "bracket only rises 24 mm.",
            )
        if self.servo_screw_depth_mm >= self.wall_thickness_mm:
            raise ShoulderBracketDesignError(
                DesignStatus.WALL_TOO_THIN,
                f"A {self.servo_screw_depth_mm:.2f} mm blind hole in a "
                f"{self.wall_thickness_mm:.2f} mm wall leaves no floor.",
            )
        for screw_x, screw_z in self.servo_screw_positions:
            if self.cavity_x_min_mm <= screw_x <= self.cavity_x_max_mm:
                raise ShoulderBracketDesignError(
                    DesignStatus.FEATURE_COLLISION,
                    f"A servo mounting hole at x = {screw_x:.2f} mm falls "
                    f"inside the servo slot "
                    f"({self.cavity_x_min_mm:.2f} .. "
                    f"{self.cavity_x_max_mm:.2f}), where there is no wall.",
                )

        # ---- Walls have to stand on the plate -----------------------------
        if (
            self.wall_x_min_mm < self.plate_x_min_mm - 1e-9
            or self.wall_x_max_mm > self.plate_x_max_mm + 1e-9
        ):
            raise ShoulderBracketDesignError(
                DesignStatus.FEATURE_COLLISION,
                f"The walls span x {self.wall_x_min_mm:.2f} .. "
                f"{self.wall_x_max_mm:.2f} mm but the base plate only reaches "
                f"{self.plate_x_min_mm:.2f} .. {self.plate_x_max_mm:.2f}.",
            )
        if self.wall_outer_y_mm > self.plate_half_y_mm + 1e-9:
            raise ShoulderBracketDesignError(
                DesignStatus.FEATURE_COLLISION,
                f"The walls reach y = {self.wall_outer_y_mm:.2f} mm but the "
                f"base plate only reaches {self.plate_half_y_mm:.2f}.",
            )

        # ---- Turntable screws must miss the walls and stay on the plate ----
        radius = self.turntable_bolt_clearance_mm / 2.0
        for bolt_x, bolt_y in self.turntable_bolt_positions:
            if abs(bolt_y) + radius > self.wall_inner_y_mm:
                raise ShoulderBracketDesignError(
                    DesignStatus.FEATURE_COLLISION,
                    f"A turntable screw at y = {bolt_y:.2f} mm lands under a "
                    f"wall, whose inner face is at "
                    f"{self.wall_inner_y_mm:.2f} mm. There would be no way to "
                    "get a driver to it. Bring the pattern inboard along Y or "
                    "outboard past the walls.",
                )
            if (
                bolt_x - radius < self.plate_x_min_mm + self.min_wall_thickness_mm
                or bolt_x + radius > self.plate_x_max_mm - self.min_wall_thickness_mm
            ):
                raise ShoulderBracketDesignError(
                    DesignStatus.WALL_TOO_THIN,
                    f"A turntable screw at x = {bolt_x:.2f} mm leaves less "
                    f"than {self.min_wall_thickness_mm:.2f} mm of plate edge.",
                )

        # ---- The cable slot must not undercut a wall or a screw -----------
        slot_x_max = self.plate_x_min_mm + self.cable_slot_x_mm
        for bolt_x, bolt_y in self.turntable_bolt_positions:
            if bolt_x - radius < slot_x_max and abs(bolt_y) < self.cable_slot_y_mm / 2.0:
                raise ShoulderBracketDesignError(
                    DesignStatus.FEATURE_COLLISION,
                    f"The cable slot reaches x = {slot_x_max:.2f} mm and would "
                    f"break into the turntable screw at "
                    f"({bolt_x:.2f}, {bolt_y:.2f}).",
                )
        if self.cable_slot_y_mm / 2.0 >= self.wall_inner_y_mm:
            raise ShoulderBracketDesignError(
                DesignStatus.FEATURE_COLLISION,
                f"The cable slot is {self.cable_slot_y_mm:.2f} mm wide and "
                f"would cut into the walls at "
                f"{self.wall_inner_y_mm:.2f} mm.",
            )

        # ---- The idler axle has to reach its bearing ----------------------
        if self.idler_axle_length_mm <= self.idler_bearing_width_mm:
            raise ShoulderBracketDesignError(
                DesignStatus.INVALID_PARAMETER,
                f"The idler axle is {self.idler_axle_length_mm:.2f} mm long "
                f"but has to pass through a "
                f"{self.idler_bearing_width_mm:.2f} mm bearing and span the "
                "gap to it.",
            )
        if self.plug_boss_diameter_mm <= self.idler_axle_diameter_mm:
            raise ShoulderBracketDesignError(
                DesignStatus.INVALID_PARAMETER,
                f"The idler boss ({self.plug_boss_diameter_mm:.2f} mm) must be "
                f"wider than the axle it carries "
                f"({self.idler_axle_diameter_mm:.2f} mm).",
            )
        return DesignStatus.OK

    # =====================================================================
    # Reporting
    # =====================================================================
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

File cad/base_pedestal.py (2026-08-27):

"""
Base pedestal -- a monolithic U-clamp that wraps the desk edge and carries the
base yaw joint.

Run directly to write ``cad/output/base_pedestal.stl``::

    python3 -m cad.base_pedestal
    python3 -m cad.base_pedestal --output /tmp/pedestal.stl
    python3 -m cad.base_pedestal --report      # dimensions only, no export

Shape
-----
One solid body in the shape of a C, seen from the side, with a servo turret
rising from the top arm::

                    +----------+  z = +70   bearing seat in the top face
                    |  servo   |
                    |  turret  |
        +-----------+----------+---------+  z = +15   top arm top
        |///|  pads      cavity opening  |  z =   0   desk surface
        |///+------------------+---------+
        |///|                            |
        |sp |        throat (desk)        |
        |ine|                            |
        |///+------------------+---------+  z = -45   bottom arm top
        |///|      nut pocket  | O bolt  |
        +---+------------------+---------+  z = -60   bottom arm underside
         x=-45   x=-30                x=+30
                  ^ desk edge

Local frame: the origin sits **on the yaw axis at the desk's top surface**, so
``z = 0`` is the desk plane and ``+X`` points inward over the desk. The desk
edge is therefore at ``x = -servo_shaft_offset_from_edge_mm``. This choice is
what lets ``ArmGeometry.base_height_mm`` (desk surface to shoulder pivot) and
the clamp geometry share one datum without a conversion step.

Why a turret rather than a thick arm
------------------------------------
The DS3218 is 40.5 mm tall, and with print clearance, the shaft boss, a
ceiling and the bearing seat it needs 55.5 mm of housing. A 15 mm top arm
cannot contain it. Thickening the arm to 55 mm would make the part a slab
rather than a C-profile and triple its material, so the arm stays thin and the
servo lives in a turret above it, reaching the 70 mm pedestal height exactly.

Why the screw points up
-----------------------
The nut is captive in a pocket in the bottom arm's **underside**; the screw
threads up through it, and its tip carries a printed pressure foot that bears
on the desk's underside. The knob hangs below on the screw's head. A screw
entering from the top of the bottom arm would press against nothing and could
not clamp at all.

Why gussets rather than fillets
-------------------------------
The two inner corners of the U carry the whole load path and want stress
relief, but a swept fillet is the most fragile operation to re-run when an
upstream dimension moves -- and every dimension here derives from
``src/geometry.py`` precisely so that it *can* move. Triangular gussets give
most of the benefit and always regenerate.

Sizing philosophy
-----------------
Nothing below is a magic number. The clamp's width is derived from what the
servo cavity and bearing seat need; the screw is placed as far outboard as the
pressure foot allows, because that simultaneously shortens the bottom arm's
cantilever and lengthens the lever it resists tipping with.
:meth:`PedestalParameters.validate` re-checks every clearance and refuses to
build a part that would print with a wall thinner than specified, a pocket
breaking into another, or a screw too short to reach the desk.

Units are millimetres throughout, matching ``src.geometry`` and STL.

.. warning::
   Several ``ServoSpec`` fields this part depends on -- notably the mounting
   flange span, ear position and shaft offset -- are UNVERIFIED placeholders.
   See ``ServoSpec.UNVERIFIED_FIELDS``. The generated STL is geometrically
   valid, but measure a real DS3218 before printing for final assembly.
"""

from __future__ import annotations

import argparse
import math
import sys
from dataclasses import dataclass
from pathlib import Path
from typing import Optional, Tuple

from build123d import Align, Box, Cylinder, Part, Pos, Rot, export_stl

from cad._design import DesignRuleError, DesignStatus
from cad._primitives import hex_prism, right_triangle_prism
from src.geometry import (
    DEFAULT_ARM,
    DEFAULT_HARDWARE,
    ArmGeometry,
    HardwareSpec,
)

__all__ = [
    "DesignStatus",
    "PedestalDesignError",
    "PedestalParameters",
    "build_pedestal",
    "export_pedestal",
    "DEFAULT_STL_PATH",
]

#: Where ``python3 -m cad.base_pedestal`` writes by default.
DEFAULT_STL_PATH = Path(__file__).resolve().parent / "output" / "base_pedestal.stl"

#: (x_min, x_max, y_min, y_max) of one anti-slip pad recess, in mm.
PadRect = Tuple[float, float, float, float]


class PedestalDesignError(DesignRuleError):
    """
    Raised when a parameter set would produce an unbuildable pedestal.

    Carries a :class:`~cad._design.DesignStatus` naming the violated
    constraint, so a caller sweeping parameters can tell "servo too big" from
    "clamp screw too short".
    """
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

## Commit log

2026-08-22 Phase A: kinematics simulation stack (32/32 tests passing)
2026-08-22 Migrate to Python 3.10+ and add Phase B/D dependencies
    build123d declares requires-python ">=3.10,<3.15", which is incompatible
    with the Python 3.9 environment Phase A was developed against. Since
    Raspberry Pi OS Bookworm ships 3.11 and Trixie ships 3.13, 3.9 support was
    not buying anything for the deployment target, so it is dropped rather than
    worked around with a second CAD-only environment.
    - CI matrix moves from 3.9-3.12 to 3.10-3.13.
    - requirements.txt gains opencv-contrib-python (the contrib build is
    required: cv2.aruco is not in the core wheel) and build123d.
    - opencv is pinned below 5.0 deliberately; OpenCV 5.x is a major release
    and its ArUco API surface has not been validated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
2026-08-22 Session B.1: image acquisition abstraction (71 tests)
    Every Phase B vision consumer (ArUco calibration, YOLO detection, homography
    fitting) will take an ImageSource rather than touching cv2.VideoCapture
    directly, so the pipeline stays testable on a machine with no camera.
    src/image_source.py
    - ImageSource ABC using a template-method split: public open/get_frame/close
    handle lifecycle tracking and frame validation, subclasses implement
    _open_impl/_read_frame/_close_impl. Every source then fails the same way
    for the same reasons, and a subclass that breaks the uint8 (H, W, 3) BGR
    contract is caught at the boundary rather than inside OpenCV downstream.
    - SourceStatus enum +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
2026-08-22 Session D.1: parametric base pedestal (76 tests)
    src/geometry.py
    Extends the single source of truth with off-the-shelf hardware, so cad/
    can declare no dimensions of its own:
    - ServoSpec, BearingSpec, FastenerSpec, BaseStack, HardwareSpec, and the
    DEFAULT_HARDWARE singleton alongside DEFAULT_ARM.
    - DS3218 body envelope (40 x 20 x 40.5 mm), mass, gear ratio, torque and
    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
    [base_pedestal.stl]
2026-08-22 Session D.1b: replace drilled flange with a desk-edge clamp
    The user does not want holes in the desk, so the M4 bolt-down flange is gone
    and the arm now clamps to the desk edge. The pedestal's internals -- servo
    cavity, retention shelf, shaft bore, bearing seat -- are unchanged; only the
    mounting changed, and test_pedestal_internals_survived_the_clamp_redesign
    pins those dimensions so a future edit cannot quietly disturb them.
    - DeskClampSpec: the clamp's full specification plus its mechanics.
    torque_to_preload_factor_m() uses the power-screw relation rather than a
    lumped nut factor, so the M8 thread pitch genuinely appears in the model
    (test_coarser_thread_giv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
    [base_pedestal.stl, desk_clamp_knob.stl, desk_clamp_lower_jaw.stl]
2026-08-22 Session B.2: camera intrinsic calibration (100 tests)
    Lens distortion is not projective -- it bends straight lines -- so fitting the
    Phase B pixel-to-desk homography to raw pixels would smear that error across
    the workspace, worst at the frame edges where the desk corners live.
    Calibrating first keeps the homography solving the problem it can solve.
    src/camera_calibration.py
    - CalibrationTarget, CameraIntrinsics (with JSON round-trip and a schema
    version), Calibrator (add_frame / calibrate / undistort), and a
    CalibrationStatus enum following the IKStatus / SourceStatus pattern.
    - CalibrationTarget documents loudly that rows/cols count INNER CORNERS,
    and rejects a square patt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
2026-08-22 Session D.1c: rewrite the pedestal as a monolithic U-clamp
    D.1b built the clamp as a cylinder with a horizontal wing bolted beside it --
    a tower with a side arm, not a clamp. This is a full rewrite as a single
    C-profile body: top arm, spine, bottom arm, servo turret and both gussets are
    one solid, with no bolted joint anywhere in the load path.
    The servo/bearing internals are carried over from D.1 unchanged;
    test_pedestal_internals_survived_the_u_clamp_rewrite pins them.
    Three specified numbers could not be built, and were resolved with the user
    rather than worked around:
    - **A 15 mm top arm cannot contain a 40.5 mm servo.** It needs 55.5 mm once
    clearance, the shaft boss, a ceiling and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
    [base_pedestal.stl, desk_clamp_lower_jaw.stl, desk_clamp_pressure_foot.stl]
2026-08-22 Session D.1c-assembly: whole-assembly preview on a desk
    Individual parts each pass their own design rules, but nothing checked that
    they fit together on a real desk. cad/assembly_preview.py places every part at
    the position ArmGeometry actually specifies, drops a desk slab into the
    clamp's throat, and extends the arm's links at their zero pose. It exports
    both a single STL (viewable in GitHub's 3D preview) and a PNG pairing a side
    elevation with an isometric.
    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
    [assembly_preview.stl]
2026-08-23 D.1d fix 1: align the base frame to the real hardware stack
    The brief diagnosed the floating L1 placeholder as base_height_mm being a
    stale Phase A value, with the servo shaft output "higher than 100 mm". It is
    not: the shaft output sits at z = 63.0 mm and the turret top at 69.5 mm, both
    well BELOW the 100 mm shoulder pivot. Measured before changing anything.
    The 30.5 mm gap in the D.1c preview is BaseStack -- the thrust bearing's proud
    height, the yaw turntable and the shoulder bracket -- none of which exists yet
    to be drawn. Setting base_height_mm to 70 as the brief proposed would leave
    40 mm of pedestal budget for a servo needing 55.5 mm and fails outright with
    FEATURE_COLLISION; it woul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
    [assembly_preview.stl, base_pedestal.stl]
2026-08-23 D.1d fix 2: correct the friction model and give the foot a swivel
    The D.1c preview showed the knob hanging clear below the bottom arm, which
    meant torque_to_preload_factor_m was charging collar friction at a knob boss
    bearing on the clamp -- a contact the U-clamp does not have. The load path is
    screw, captive nut, nut pocket; a knob that reached the arm would jam against
    it instead of loading the desk.
    The brief asked to remove the collar term and use the standard K=0.2 nut
    factor. Those two are not the same thing: K lumps thread AND head-bearing
    friction into one number (verified: K about 0.2 for dry steel-on-steel, range
    0.10-0.30), so it does not remove a collar, it hides one. Removing t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
    [assembly_preview.stl, desk_clamp_knob.stl, desk_clamp_pressure_foot.stl]
2026-08-23 D.1d fix 3: raise the safe-reach ceiling to 88%
    D.1c moved the base 30 mm inward to clear the U-clamp, which improved the
    worst desk corner from 848.5 mm to 827.6 mm -- a small reach win. But that
    still sat outside safe_reach_mm at 85% of full extension (807.5 mm), so
    coverage_report() printed "Full-desk reachable? False" for an arm that was
    inside the 89% envelope PROOF_OF_CONCEPT section 2.1 sized the links against.
    A recommended operating radius that excludes the corners the arm was built to
    reach is not a caution, it is a contradiction.
    The brief specified 87%. That is 826.50 mm, which is 1.09 mm SHORT of the
    827.59 mm corner -- the invariant test the brief also asked for would have
    fa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
    [geometry.py]
2026-08-27 D.2a yaw turntable: swap the yaw bearing for one a servo horn fits through
    The turntable is driven by the base yaw servo through a bought aluminium horn
    and rides the pedestal's thrust bearing. Designing it exposed a blocking fault
    in the bearing D.1 chose.
    The 608ZZ sat on the yaw axis directly above the servo's output shaft,
    occupying the entire 7 mm between the shaft crown at z = 63.0 and the
    turntable's underside at z = 70.0 -- and its bore is 8 mm. A 25T horn is
    19.7-25 mm across (the DS3218's spline itself is 5.9 mm, confirmed), so there
    was nowhere in the stack for the coupling. Nothing gripped the 608's inner race
    either, which meant it was not acting as a bearing at all.
    Replaced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
    [base_pedestal.stl, yaw_turntable.stl]
2026-08-27 D.2b shoulder bracket: the stack now closes on base_height_mm by construction
    A clevis on the yaw turntable holding the second DS3218, whose output shaft is
    the shoulder pitch axis. Its whole reason for existing is the last line of the
    budget: pedestal 69.5 + bearing proud 0.5 + turntable 6.0 + this rise 24.0 =
    100.000 mm, asserted against ArmGeometry.base_height_mm rather than against a
    copy of the number. HardwareSpec now also refuses to hold a BaseStack budget
    that disagrees with the parts it is budgeting for.
    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
    [shoulder_bracket.stl, shoulder_idler_plug.stl]
2026-08-27 D.2c upper arm: a yoke, because a single flange would break the kinematics
    L1, 400 mm shoulder axis to elbow axis: a yoke at the shoulder, a hollow
    40 x 25 x 3 mm beam, and a housing at the elbow carrying the third DS3218.
    Completes the run from desk clamp to elbow, so the assembly preview now places
    real parts everywhere except L2 and L3.
    Why a yoke rather than the flange the brief specified. The shoulder servo's
    horn face sits 35.5 mm off the yaw axis, so a link hung off one flange would
    centre roughly 50 mm to one side -- and forward_kinematics.py has no term for a
    shoulder offset, so that distance would become systematic error in every TCP
    position the software computes. Two flanges str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
    [assembly_preview.stl, upper_arm.stl]
2026-08-27 D.2 docs: correct three stale references the bearing swap left behind
    The base-height budget table still named the 608ZZ, the "sources of truth"
    list still named it as the only bearing, and the print-orientation table still
    said "the three parts". None of these change a design decision; they were just
    describing a repo that no longer exists.
2026-08-27 D.2 preview: put the shoulder idler bearing in the seat cut for it
    It was drawn a full bearing width inboard, overlapping the idler plug's boss
    by 792 mm3. The yoke's far flange cuts its seat inward from the flange's inner
    face, so the ring starts at that face minus the bearing's width, not at the
    face itself.
    Missed because the collision test deliberately covers the printed parts only:
    the bearings are drawn at their true outside diameter while their seats are cut
    under it, so each legitimately overlaps its housing by the press-fit annulus.
    That gap is now closed by checking each bearing against the exact annulus
    volume rather than merely asserting the overlap is small -- so a bearing draw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
    [assembly_preview.stl]
